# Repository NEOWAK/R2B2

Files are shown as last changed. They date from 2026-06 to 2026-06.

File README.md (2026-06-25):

# R2B2

    

## 📑 Table of Contents

- [Description](#description)
- [Screenshots](#screenshots)
- [Quick Start](#quick-start)
- [Project Structure](#project-structure)
- [Contributors](#contributors)
- [Contributing](#contributing)
- [License](#license)

## 📝 Description

R2B2 — Robot autonome ramasseur de balles de tennis

## 📸 Screenshots

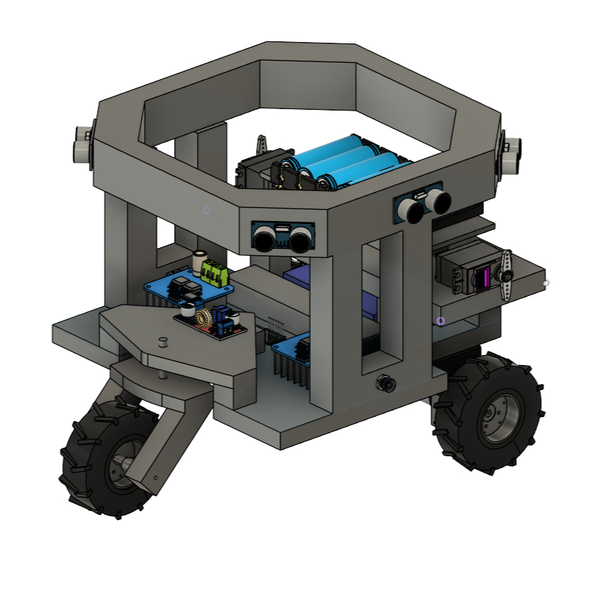
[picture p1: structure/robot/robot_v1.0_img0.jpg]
robot 3D


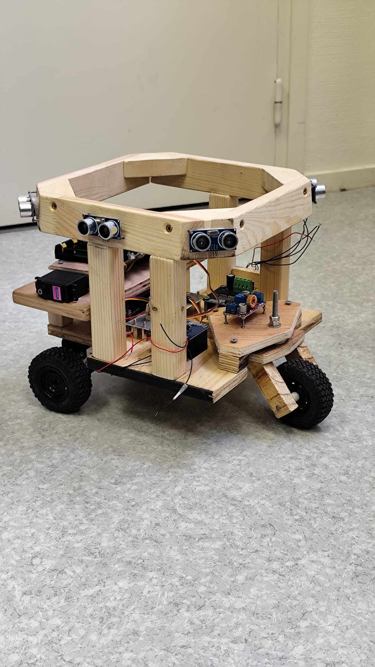
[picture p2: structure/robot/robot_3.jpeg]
robot real


## ⚡ Quick Start

```bash

# 1. Clone the repository
git clone https://github.com/NEOWAK/R2B2.git

# See the Development Setup section below
```

## 📁 Project Structure

```
.
├── LICENSE
├── docs
│   ├── cdc
│   │   ├── Rapport_CDC.pdf
│   │   └── Rapport_CDC.zip
│   ├── presentation
│   │   ├── R2B2.pdf
│   │   └── R2B2.pptx
│   └── rapport
│       ├── Rapport_PROJET.zip
│       └── Rapport_PROJETELEC_ROBOT_TENNIS.pdf
├── firmware
│   ├── esp32c3
│   │   ├── v0_1.ino.ino
│   │   └── v0_2.ino.ino
│   └── fpga
│       ├── driver
│       │   └── Motor_Controller.vhd
│       ├── pid
│       │   ├── adc0
│       │   │   ├── adc0.bsf
│       │   │   ├── adc0.cmp
│       │   │   ├── adc0.html
│       │   │   ├── adc0.ppf
│       │   │   ├── adc0.xml
│       │   │   ├── adc0_bb.v
│       │   │   ├── adc0_generation.rpt
│       │   │   ├── adc0_inst.v
│       │   │   ├── adc0_inst.vhd
│       │   │   └── synthesis
│       │   │       └── ...
│       │   ├── adc0.qsys
│       │   ├── adc0.sopcinfo
│       │   ├── adc_period.vhd
│       │   ├── baud_gen.vhd
│       │   ├── motor_controller.vhd
│       │   ├── top.vhd
│       │   ├── uart_framer.vhd
│       │   ├── uart_mux.vhd
│       │   ├── uart_rx.vhd
│       │   ├── uart_tx.vhd
│       │   ├── xor.qpf
│       │   ├── xor.qsf
│       │   ├── xor.qws
│       │   └── xor_assignment_defaults.qdf
│       ├── pince
│       │   └── pince_controlleur.vhd
│       └── ultrason
│           └── ultrason.vhd
├── hardware
│   ├── alimentation
│   │   ├── alimentation_0.heic
│   │   └── alimentation_1.heic
│   ├── cao
│   │   ├── pince.f3z
│   │   └── robot.f3z
│   └── pcb
│       ├── pads_layout.pdf
│       ├── pads_logic.pdf
│       ├── pcb.cir
│       ├── pcb.sch
│       ├── pcb_v1.pcb
│       └── pcb_v2.pcb
├── scripts
│   └── courbe_paramétrique.ggb
├── software
│   ├── dashbord
│   │   ├── Capture d’écran du 2026-05-18 06-51-23.png
│   │   └── dashboard.py
│   ├── detection
│   │   ├── esp32_camera.ino
│   │   └── modele_ia.zip
│   └── monitor
│       ├── img
│       │   ├── adc_mesure_5V.png
│       │   ├── adc_mesure_paliers.png
│       │   └── oscilo_mesure_5V.BMP
│       ├── monitor.py
│       └── monitor_v2.py
└── structure
    ├── pince
    │   ├── Capture d’écran du 2026-05-18 06-07-12.png
    │   ├── Capture d’écran du 2026-05-18 06-07-25.png
    │   ├── Capture d’écran du 2026-05-18 06-07-59.png
    │   ├── Capture d’écran du 2026-05-18 06-08-07.png
    │   ├── pince3D_01_square.jpg
    │   └── pinceo.jpg
    └── robot
        ├── robot_0.jpeg
        ├── robot_1.jpeg
        ├── robot_2.jpeg
        ├── robot_3.jpeg
        └── robot_v1.0_img0.jpg
```

## 👥 Contributors

Thanks to everyone who has contributed to this project:

<p align="left">
<a href="https://github.com/NEOWAK" title="NEOWAK">NEOWAK</a>
</p>

[See the full list of contributors →](https://github.com/NEOWAK/R2B2/graphs/contributors)

## 👥 Contributing

Contributions are welcome! Here's the standard flow:

1. **Fork** the repository
2. **Clone** your fork: `git clone https://github.com/NEOWAK/R2B2.git`
3. **Branch**: `git checkout -b feature/your-feature`
4. **Commit**: `git commit -m 'feat: add some feature'`
5. **Push**: `git push origin feature/your-feature`
6. **Open** a pull request

Please follow the existing code style and include tests for new behavior where applicable.

## 📜 License

This project is licensed under the **MIT** License.

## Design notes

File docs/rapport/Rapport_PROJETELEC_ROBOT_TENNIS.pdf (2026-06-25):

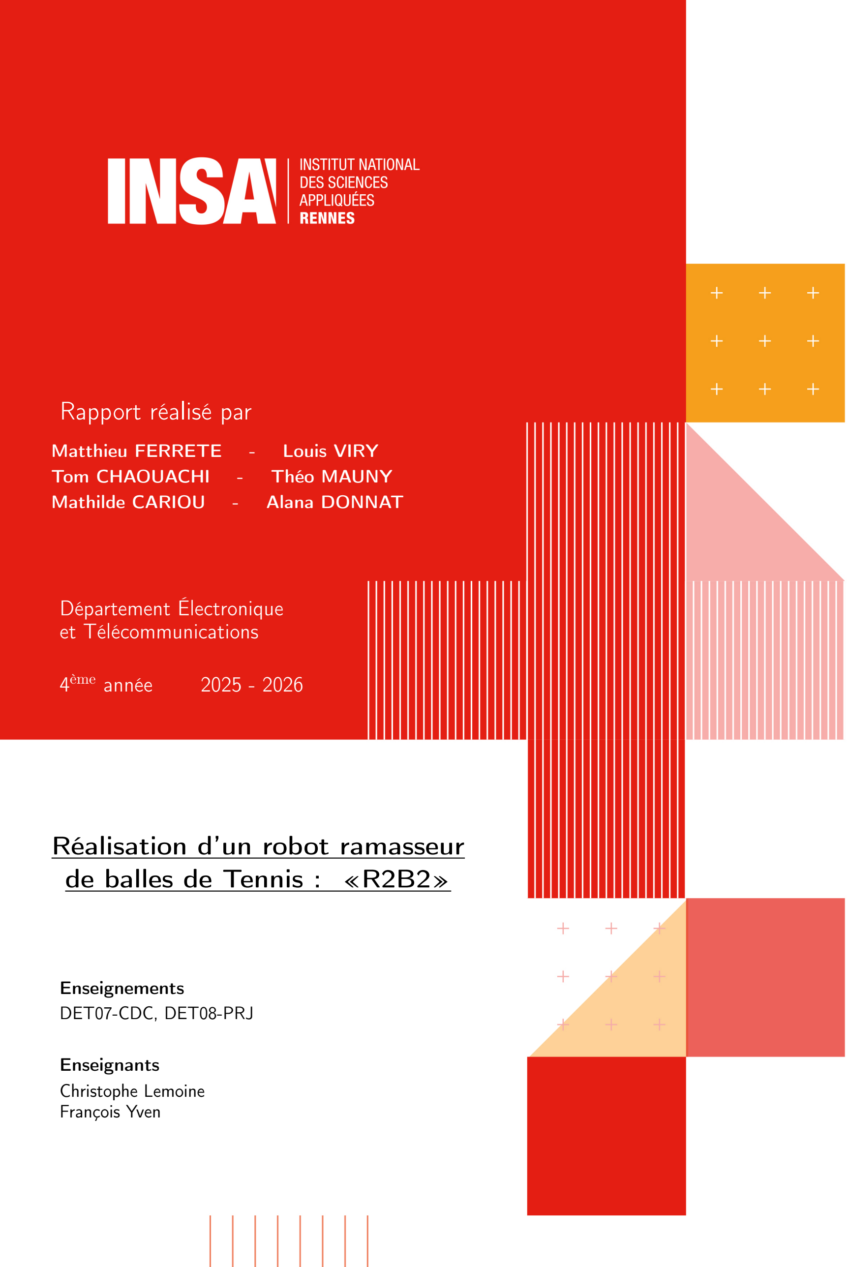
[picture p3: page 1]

## Rapport réalisé par

Matthieu FERRETE | - | Louis VIRY
Tom CHAOUACHI | - | Théo MAUNY
Mathilde CARIOU | - | Alana DONNAT

## Département Électronique et Télécommunications

4

## ème année 2025 - 2026

## Réalisation d’un robot ramasseur de balles de Tennis : «R2B2»

Enseignements
DET07-CDC, DET08-PRJ

Enseignants
Christophe Lemoine
François Yven

# Remerciements

Nous tenons à remercier les enseignants qui encadrent ce projet pour leur accompagnement tout au long de cette année.

Nous remercions M. Christophe LEMOINE pour son encadrement pédagogique et M. François YVEN pour son suivi en tant que tuteur de projet.

Nous tenons à adresser nos remerciements les plus sincères à M. Gilles PICOULT, dont la présence a été déterminante dans la progression de ce projet. Ses conseils techniques avisés, sa disponibilité, les solutions qu’il nous a proposées face aux difficultés rencontrées, la fabrication des PCB, ainsi que ses encouragements ont été d’une valeur inestimable tout au long de la réalisation de R2B2.

R2B2

### Robot Ramasseur de Balles de Tennis

# Table des matières

1 Introduction | 7
2 Présentation du projet | 7
3 Cahier des charges | 13
4 Architecture générale du système | 16

5 Module de déplacement et motorisation | 19
5.3.2 | Première approche : circuit de conditionnement analogique (non conservé) | 23
6 Module de détection et navigation | 28
7 Conception mécanique et CAO | 34

8 Système de batteries et gestion d’énergie | 40
9 Supervision et interface opérateur | 42
10 Gestion | 46
11 Démonstration | 50

12 Conclusion | 54
13 Bibliographie | 55

# 1. Introduction

L’évolution technologique dans le domaine du sport a considérablement transformé la pratique de haut niveau comme celle des amateurs. Si les équipements ont bénéficié d’innovations majeures en science des matériaux, la logistique même du jeu de tennis est restée remarquablement classique : la gestion des balles sur le terrain repose encore presque exclusivement sur l’intervention humaine.

Le tennis est un sport structurellement fragmenté : le temps de jeu effectif ne représente qu’une fraction minime du temps total, déséquilibre encore aggravé lors des entraînements amateurs où le ramassage des balles peut mobiliser jusqu’à 20% à 30% d’une séance. Ces balles immobiles constituent par ailleurs un risque physique avéré, une part significative des blessures survenant non pas à cause de l’effort, mais par un appui instable sur une balle qui traîne.

La dimension inclusive mérite également d’être soulignée : pour les joueurs en fauteuil roulant, le ramassage impose des manœuvres supplémentaires et une flexion du tronc qui peut s’avérer éprouvante, voire impossible selon la pathologie du joueur.

Notre projet, baptisé R2B2, vise à concevoir une solution mécatronique autonome opérant en continu durant le match. Contrairement aux rares solutions existantes qui nettoient le terrain en fin de session, R2B2 cohabite avec les joueurs, identifie les balles mortes et les collecte en temps réel, sans jamais interférer avec le jeu ni gêner les déplacements des sportifs — ce qui impose des contraintes fortes en détection, navigation, sécurité et réactivité.

Ce document présente la démarche de conception de R2B2 : après une analyse du besoin et un état de l’art, nous décrirons l’architecture générale puis chacun des sous-systèmes — déplacement, détection, ramassage, gestion d’énergie et supervision — avant de conclure par le bilan et les perspectives d’évolution.

# 2. Présentation du projet

## 2.1 Analyse du besoin

Pour justifier la pertinence de ce projet, nous avons analysé les impacts du ramassage manuel sous trois angles fondamentaux : l’efficacité temporelle, la sécurité physique et l’inclusion sociale.

### 2.1.1 Optimisation du temps de jeu

Le tennis souffre d’un ratio temps de jeu sur temps de présence particulièrement faible. Une étude statistique relayée par le Wall Street Journal a mis en lumière que sur une rencontre professionnelle d’une durée de trois heures, le temps de jeu effectif ne représente que 17,5% du temps total, soit à peine 21 minutes d’action réelle [1].

Ce constat est encore plus sévère lors des entraînements amateurs. Lorsqu’un joueur effectue une série de services ou un exercice au panier, le ramassage manuel des 50 à 100 balles dispersées peut prendre entre 5 et 8 minutes. Sur une séance d’une heure, la répétition de cette tâche empiète sur le temps de pratique de 20% à 30%. L’automatisation de ce processus permettrait de récupérer ce temps perdu pour le consacrer à l’apprentissage technique et au plaisir du jeu.

### 2.1.2 Sécurité et prévention des blessures

La présence de balles immobiles sur la surface de jeu constitue un risque avéré pour l’intégrité physique des joueurs. Les déplacements au tennis sont caractérisés par des courses latérales, des reprises d’appuis violentes et des reculs précipités pour se replacer en fond de court. Une part significative des accidents survient non pas à cause de l’effort lui-même, mais par un appui instable sur une balle qui traîne.

Si un joueur pose le pied sur une balle lors d’un de ces mouvements, la cheville subit une torsion immédiate. Selon les données de la Fédération Française de Tennis et des études en traumatologie sportive, l’entorse de la cheville représente environ 25% des blessures recensées au tennis [2]. En assurant un nettoyage continu de la zone d’évolution, notre robot agit comme un dispositif de sécurité active permettant de réduire fortement la probabilité de chute et de lésion ligamentaire.

### 2.1.3 Accessibilité et Handisport

L’aspect inclusif est un pilier central de notre réflexion. Pour les joueurs de tennis en fauteuil roulant, la contrainte du ramassage est décuplée. La biomécanique du ramassage en position assise impose des manœuvres supplémentaires avec le fauteuil et une flexion du tronc qui peut s’avérer éprouvante physiquement, voire impossible selon la pathologie du joueur.

Cette difficulté constitue parfois un frein à la pratique ou une source de découragement pour les débutants. En déléguant cette tâche à un système autonome, nous redonnons de l’autonomie aux joueurs en situation de handicap, leur permettant de se focaliser uniquement sur leur performance sportive et leur plaisir de jeu, sans dépendre d’une tierce personne.

## 2.2 État de l’art

Avant de définir notre solution, nous avons étudié les technologies existantes — manuelles et automatisées — afin d’identifier les lacunes du marché actuel et les bonnes pratiques à conserver.

### 2.2.1 Les solutions manuelles

- Le tube de ramassage

C’est un tube en plastique ou en métal muni d’un clapet anti-retour. Pour faire entrer la balle, on appuie simplement dessus.

Avantage : Très peu coûteux (moins de 20 €), facilement transportable, évite de se baisser complètement.
Inconvénient : Effort physique répétitif, ramassage balle par balle, aucune automatisation possible.
- Le rouleau de ramassage

Il s’agit d’un rouleau que l’on pousse sur le court, conçu avec des barreaux souples qui s’écartent lorsqu’on roule sur une balle, permettant de la récupérer et de la stocker dans un panier intégré.

Avantage : Ramassage rapide, grande capacité de stockage (jusqu’à 60 balles). Inconvénient : Encombrant, nécessite toujours une action humaine continue, inutilisable pendant le jeu.

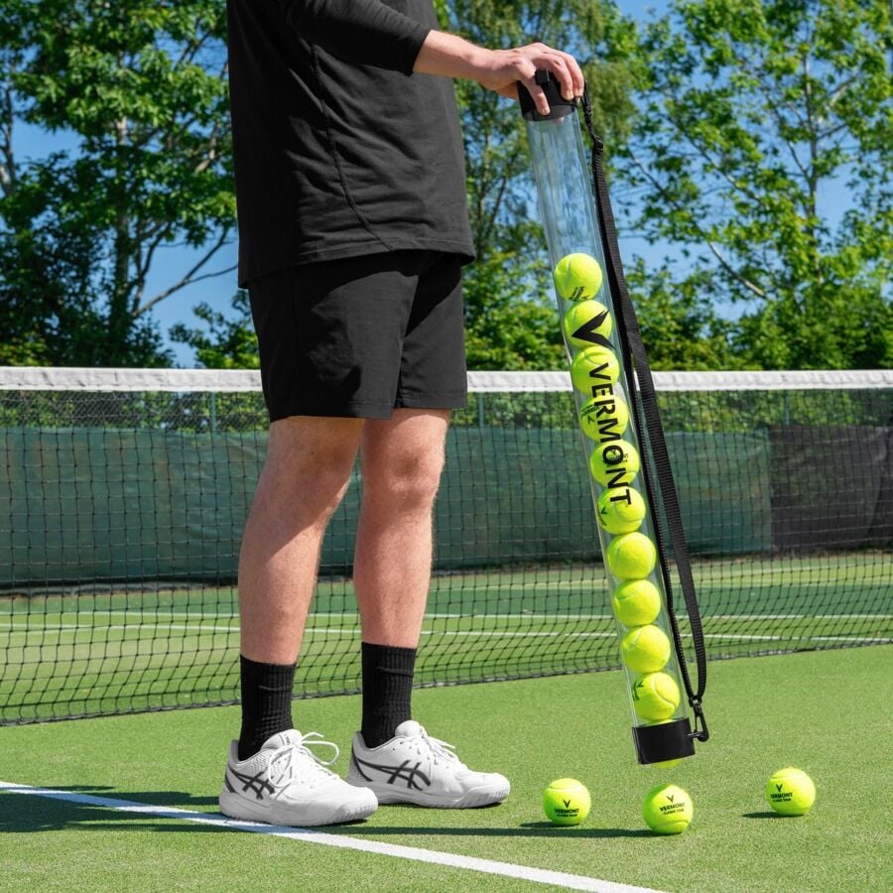
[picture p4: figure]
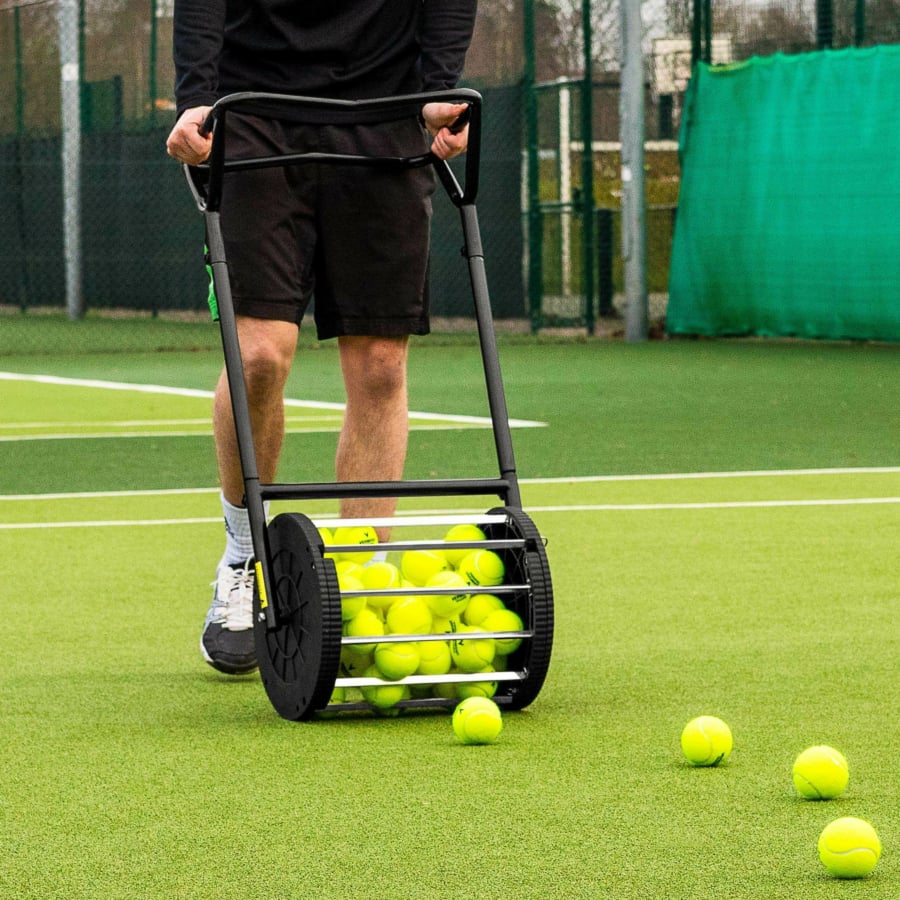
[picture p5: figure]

Figure 1 – Tube de ramassage | Figure 2 – Rouleau de ramassage

### 2.2.2 Les solutions automatisées

- Le Tennibot

Robot ramasseur autonome dont le fonctionnement s’inspire de l’aspirateur robot, adapté au tennis. Son système de navigation repose sur l’intelligence artificielle et un LIDAR 360° offrant une portée de 30 mètres [3].

Avantage : Autonomie totale — le joueur joue pendant que le robot ramasse. Inconvénient : Prix prohibitif pour un usage amateur (˜2 245 $), vitesse de ramassage lente, capacité de stockage limitée, opération uniquement hors-match.

- Le Slinger Bag

Système robotisé permettant la distribution de balles selon plusieurs paramètres : fréquence, vitesse, effets.

Avantage : Sessions d’entraînement personnalisées sans partenaire.
Inconvénient : Conçu exclusivement pour la distribution — aucune fonction de collecte.

L’utilisateur doit interrompre l’entraînement pour ramasser manuellement les balles et recharger la machine.

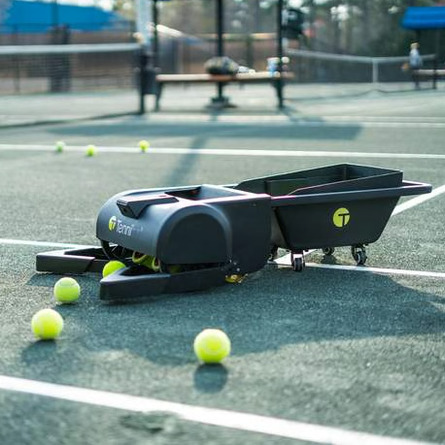
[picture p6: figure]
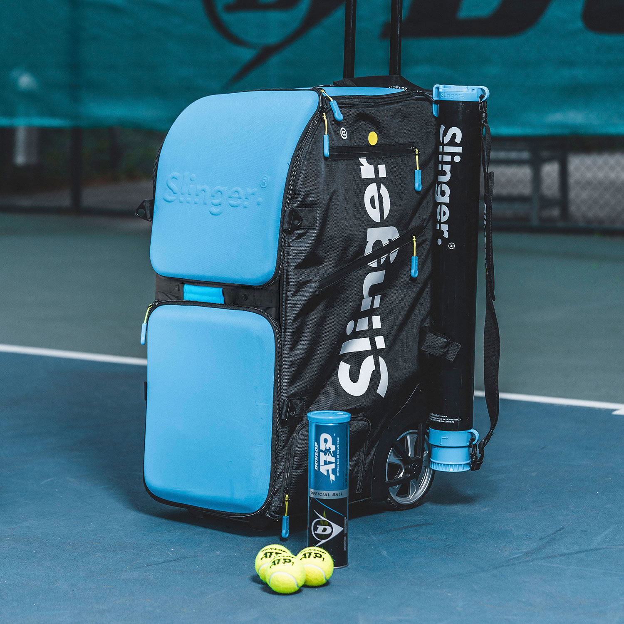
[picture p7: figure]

Figure 3 – Tennibot | Figure 4 – Slinger Bag

### 2.2.3 Positionnement de R2B2

Il apparaît que les systèmes existants présentent des limites structurelles majeures. Les outils manuels imposent une charge physique répétitive et interrompent systématiquement le jeu. Les solutions automatisées comme le Tennibot affichent un coût prohibitif et opèrent uniquement entre les sessions, pas pendant le match.

R2B2 répond à une lacune claire : aucune solution actuelle n’est à la fois abordable financièrement, capable d’opérer en temps réel pendant le jeu, et respectueuse de la sécurité des joueurs. C’est précisément l’objectif que notre projet se donne.

## 2.3 Solution retenue

Pour répondre aux besoins identifiés, notre projet se fixe quatre objectifs techniques précis qui ont guidé l’ensemble des choix de conception.

### 2.3.1 Sécurité et détection

La priorité absolue est la cohabitation homme-machine. Le robot doit cartographier son environnement immédiat pour distinguer une balle inerte d’un joueur en mouvement. Si un humain pénètre dans un rayon de 1 mètre autour du robot, le système doit déclencher un arrêt total ou une manœuvre d’évitement. La chaîne de traitement allant de la détection à l’arrêt des moteurs doit respecter une latence inférieure à 100 millisecondes, validée expérimentalement à 85 ms lors de nos tests.

### 2.3.2 Compacité et discrétion

Le robot ne doit pas devenir une nuisance visuelle ni perturber les joueurs. Sa hauteur totale est contenue sous 25 cm, lui permettant de circuler librement sous le filet et de rester hors du champ de vision direct des joueurs lors des phases de frappe. L’architecture à entraînement différentiel sur trois roues permet des demi-tours instantanés sans avance, indispensables pour s’extraire des coins du court. La motorisation est isolée phoniquement pour rester sous le seuil des 50 dB.

### 2.3.3 Performances et autonomie

Pour être efficace entre deux points, le robot doit être rapide. Une vitesse de pointe de 3 m/s est atteinte, permettant d’intervenir rapidement durant les temps morts.

L’alimentation repose sur un pack 7S1P composé de cellules Samsung INR18650-25R, offrant une tension nominale de 25,9 V (29,4 V en charge complète, coupure à 17,5 V) pour une capacité de 2 500 mAh, soit une énergie totale disponible d’environ 64,75Wh. Cette configuration garantit une autonomie suffisante pour couvrir la durée moyenne d’un match complet, tout en délivrant un courant de décharge continu pouvant atteindre 20 A pour alimenter les pics de consommation des moteurs.

### 2.3.4 Ramassage

Le système de ramassage doit être universel et robuste. Le taux de réussite de la collecte au premier passage doit dépasser 90%, même si la balle est encore légèrement en mouvement. Le réservoir embarqué est dimensionné pour contenir entre 10 et 15 balles, correspondant à la quantité généralement utilisée lors d’un cycle de jeu avant un ramassage complet.

# 3. Cahier des charges

## 3.1 Contraintes fonctionnelles

Le tableau suivant synthétise les exigences fonctionnelles retenues pour R2B2, issues de l’analyse du besoin conduite au semestre précédent.

Fonction | Exigence | Justification

Vitesse de déplacement

≥ 3 m/s, atteinte en <
4 s
Intervenir | efficacement | entre
deux points
Gabarit | Hauteur ≤ 25 cm | Passer librement sous le filet
(hauteur 91 cm au centre)
Autonomie | ≥ 2 h | Couvrir la durée moyenne d’un
match complet
Niveau sonore | ≤ 50 dB | Ne pas perturber la concentra-
tion des joueurs
Taux de collecte | ≥ 90% au 1er passage | Fiabilité opérationnelle en condi-
tion réelle
Capacité du réservoir
10 à 15 balles | Correspondance avec un cycle de
jeu standard
Budget | ≤ 120 € | Contrainte imposée par le cadre
pédagogique

Table 1 – Contraintes fonctionnelles de R2B2

## 3.2 Contraintes techniques

### 3.2.1 Niveaux logiques et alimentation

L’architecture électronique de R2B2 repose sur une cohabitation de deux domaines de tension. Le FPGA DE10-Lite opère en logique 3,3 V, tandis que les capteurs ultrasons HC-SR04 délivrent leurs signaux Echo en 5 V. Un pont diviseur résistif (R1 = 3,3 kΩ, R2 = 1,8 kΩ) est donc interposé sur chaque ligne Echo pour adapter les niveaux sans endommager les entrées du FPGA.

L’ensemble du système est alimenté par le pack 7S1P Samsung INR18650-25R (25,9 V nominal). Des régulateurs de tension assurent la distribution aux différents sous-systèmes selon leurs besoins propres.

### 3.2.2 Architecture de contrôle hybride

La répartition des tâches entre les deux cartes principales découle d’une contrainte forte : certaines opérations exigent un déterminisme temporel strict que seul un FPGA peut garantir.

- FPGA DE10-Lite : gestion temps réel des signaux PWM moteurs, lecture des encodeurs à effet Hall, pilotage des 8 capteurs ultrasons, asservissement PID.
- XIAO ESP32-C3 : logique décisionnelle de haut niveau — navigation, gestion des trajectoires, réception des coordonnées de balle depuis la caméra, relais des données de supervision vers le PC.
- XIAO ESP32-S3 Sense : acquisition et traitement d’image, pilotage du servomoteur SG90, calcul du barycentre et transmission des coordonnées.

### 3.2.3 Protocoles de communication

Les échanges inter-cartes reposent exclusivement sur l’UART, choisi pour sa simplicité d’implémentation en VHDL et sa robustesse. La trame définie entre le FPGA et l’ESP32-C3 est constituée de 8 octets : un octet de start, un octet d’état (déplacement / bras / pince), un octet de sens de marche, deux octets de consigne de vitesse et deux octets d’angle de braquage.

## 3.3 Ajustements stratégiques en cours de projet

Le périmètre fonctionnel initial a évolué au fil des réunions d’avancement. Chaque abandon a été motivé par une analyse coût-bénéfice rigoureuse, privilégiant la fiabilité du cœur de fonctionnalité sur l’exhaustivité des options.

### 3.3.1 Fonctionnalités abandonnées en début de projet

Trois fonctionnalités initialement envisagées ont été retirées dès la première révision du Gantt, le projet ayant été jugé trop ambitieux au regard du calendrier disponible [1] :

- Détection sonore des balles : l’idée d’exploiter le son d’impact balle-sol a été écartée en raison de la complexité du traitement du signal en environnement bruité extérieur (vent, bruits de match), et parce que la vision s’est révélée plus précise et moins énergivore.
- Renvoi des balles ramassées : un mécanisme de relance avait été envisagé, mais sa conception mécanique dépassait le budget et le temps disponible sans apporter de valeur déterminante à la démonstration.
- Base deux roues auto-équilibrée : le robot était initialement prévu sur deux roues avec un système de contre-balancement. Cette solution a été abandonnée car la correction continue de l’inclinaison complexifiait fortement la détection et le ramassage. Le passage à trois roues (deux motrices à l’avant, une roue folle à l’arrière) a permis de conserver l’agilité tout en garantissant la stabilité.

### 3.3.2 Remplacement du microcontrôleur principal

En cours de développement, le microcontrôleur XIAO MG24 initialement retenu pour la logique décisionnelle a présenté un dysfonctionnement matériel ne permettant plus son utilisation. Afin de ne pas bloquer l’avancement du projet, il a été remplacé par un XIAO ESP32-C3 disponible en stock.

Ce choix s’est avéré pertinent : l’ESP32-C3 offre des capacités comparables pour notre usage — communication UART, logique de navigation, gestion des entrées/sorties — sans nécessiter de refonte architecturale. L’ensemble du protocole de communication défini avec le MG24 a été conservé tel quel.

# 4. Architecture générale du système

## 4.1 Schéma de principe général

Le robot repose sur une architecture trois niveaux : acquisition sensorielle, traitement décisionnel et actionnement. Deux microprocesseurs et un FPGA se répartissent les tâches selon leur nature — temps réel strict, traitement d’image et logique de navigation — et communiquent par liaisons série UART.

Durant la phase de conception, le port USB-UART natif de l’ESP32-C3 a servi d’interface de débogage principale. Les variables internes — angle de consigne, distance estimée, état du robot — étaient transmises en continu vers un terminal série, permettant de valider le comportement du système sans instrumentation matérielle supplémentaire. Ce canal n’est pas utilisé en conditions opérationnelles.

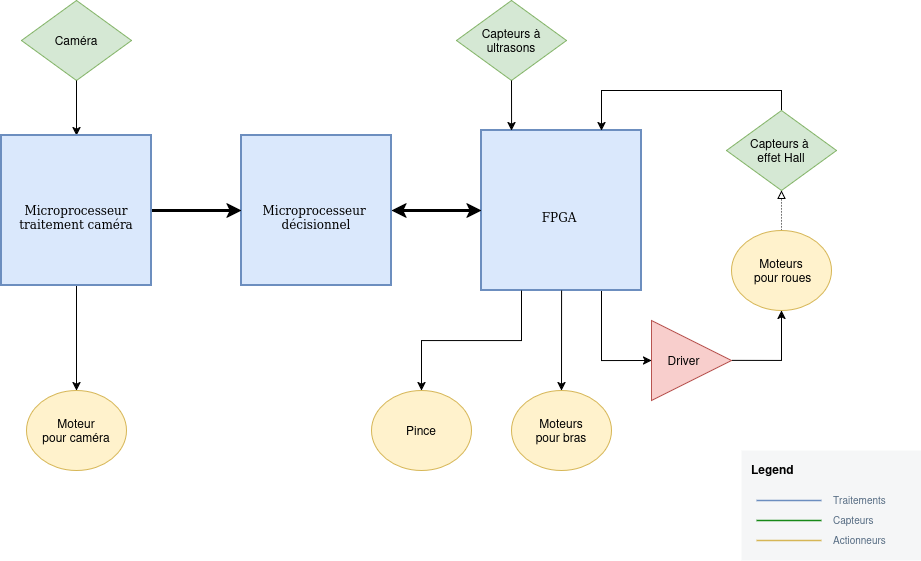
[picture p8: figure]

Figure 5 – Schéma de principe général du robot ramasseur de balles

## 4.2 Architecture de contrôle hybride FPGA + Microcontrôleur

La répartition des tâches repose sur les caractéristiques intrinsèques de chaque unité : le FPGA DE10-Lite assure la logique câblée déterministe (PID, PWM, capteurs, sécurité) en parallèle à 50 MHz, tandis que le XIAO ESP32-C3 gère la logique décisionnelle de haut niveau — navigation, séquences de collecte, arbitrage des ordres issus du module caméra.

### 4.2.1 Chaîne de perception visuelle

Un microprocesseur dédié au traitement caméra (XIAO ESP32-S3 Sense) acquiert les images via l’OV3660 et exécute l’inférence FOMO. Il transmet à l’ESP32-C3 l’angle de rotation et le seuil de distance de la balle détectée. Un moteur orienteur de caméra permet d’ajuster le champ de vision selon les consignes reçues.

### 4.2.2 Couche décisionnelle et temps réel

L’ESP32-C3 interprète les données caméra et sélectionne la stratégie courante — recherche, approche ou ramassage. Il transmet ses ordres au FPGA DE10-Lite qui les exécute en temps réel :

— Régulation PID — asservissement en vitesse de chaque roue à partir des capteurs à effet Hall ; les deux boucles s’exécutent simultanément grâce au parallélisme natif du FPGA — Génération PWM — signaux à 20 kHz pour le pont en H, avec gestion indépendante de la vitesse et du sens de rotation de chaque moteur
— Acquisition ultrason — pilotage des 8 capteurs HC-SR04 en parallèle et déclenchement de l’évitement obstacles sous 200 mm
— Séquencement de la pince — Machine à états gérant l’ouverture, la fermeture et la sécurité thermique du moteur pas à pas 28BYJ-48
— Arrêt d’urgence matériel — signal asynchrone KEY0 forçant l’extinction de tous les actionneurs en moins de 20 ns

### 4.2.3 Chaîne d’actionnement

Le FPGA pilote trois actionneurs distincts :
— Moteurs de roues — via un driver pont en H, asservis en boucle fermée PID grâce aux capteurs à effet Hall
— Moteurs de bras — déclenchés au franchissement du seuil BBOX_NEAR
— Pince — moteur pas à pas 28BYJ-48 en mode demi-pas (8 phases) pour maximiser le couple lors de la saisie

## 4.3 Outils et environnements de développement

### 4.3.1 FPGA — Intel Quartus Prime

La logique VHDL du DE10-Lite est développée sous Intel Quartus Prime Lite, certains modules ayant été simulés sous ModelSim avant intégration dans le Top_Robot pour valider chronogrammes et machines à états sans déploiement matériel systématique.

### 4.3.2 Microcontrôleurs — Arduino IDE

Les deux ESP32 sont programmés en C/C++ sous Arduino IDE avec le BSP Seeed Studio. Le modèle FOMO est déployé sous forme de bibliothèque C++ générée par Edge Impulse Studio et embarquée directement dans le firmware de l’ESP32-S3.

### 4.3.3 Supervision PC — Python

Un script Python lit le port série de l’ESP32-C3 et trace en temps réel vitesse, angle et état du robot via matplotlib, permettant de diagnostiquer les dérives PID et valider les seuils de détection sans modifier le firmware.

### 4.3.4 Conception mécanique — Autodesk Fusion 360

Le châssis et les pièces mécaniques sont modélisés sous Autodesk Fusion 360 (licence éducation). Le positionnement des composants électroniques et des capteurs est validé dans l’assemblage CAO avant toute réalisation physique.

# 5. Module de déplacement et motorisation

Le module de déplacement repose sur une chaîne de contrôle entièrement implémentée en VHDL sur le FPGA DE10-Lite, dont l’architecture est présentée en Figure 6. Une trame UART reçue de l’ESP32-C3 est décodée pour en extraire la consigne de vitesse. Celle-ci est comparée à la vitesse mesurée, fournie par le bloc Frequency extractor alimenté par le Rotation counter issu du capteur Hall. Le régulateur PI calcule la commande correctrice transmise au Driver BTS7960, qui alimente directement les moteurs. Les sections suivantes détaillent chacun de ces blocs.

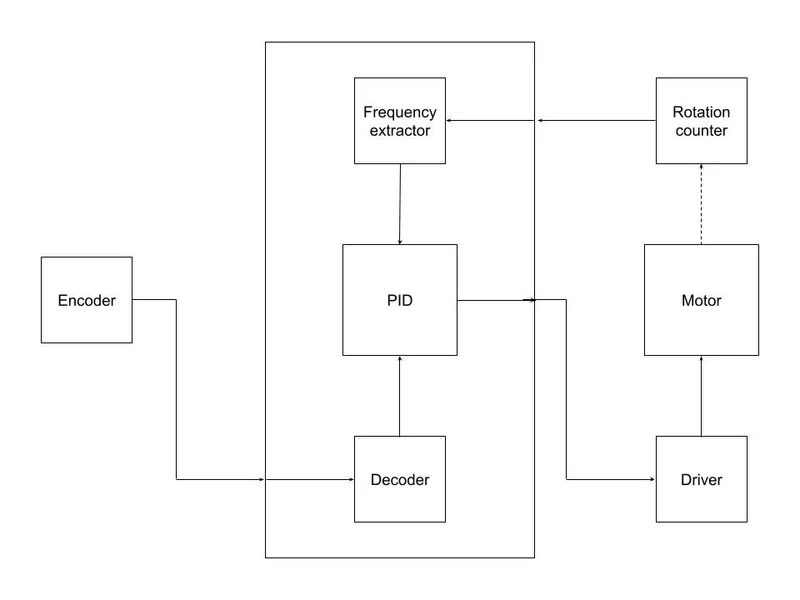
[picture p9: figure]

Figure 6 – Architecture de la chaîne de contrôle moteur sur FPGA

## 5.1 Choix et dimensionnement des actionneurs

### 5.1.1 Expression du besoin mécanique

Pour intervenir efficacement entre deux points et ne pas perturber le rythme du jeu, le robot doit atteindre une vitesse de pointe de 3 m/s — exigence fixée par le cahier des charges afin de garantir une expérience de jeu fluide et continue. Avec des roues de diamètre D = 75 mm, la vitesse de rotation minimale requise est :

nmin =

60 · v
π · D

=

60 × 3
π × 0,075

≈ 764 RPM

En tenant compte des frottements et du rendement du réducteur (η ≈ 0,75), le couple utile à délivrer est estimé à supérieur à 1 N.m par moteur.

### 5.1.2 Sélection et validation : JGB37-520 24 V 960 RPM

Le JGB37-520 24 V — 960 RPM satisfait l’ensemble des contraintes. Sa vitesse à vide produit une vitesse linéaire théorique :

vmax =

960 × π × 0,075
60

≈ 3,77 m/s

soit une marge de +25% au-dessus du seuil requis, absorbant les pertes en charge réelle. Son couple nominal de 1,5 N.m dépasse le besoin estimé, sa masse de 160 g reste compatible avec le gabarit du châssis, et son alimentation en 24 V est assurée directement par le pack batterie 7S (25,9 V nominal).

## 5.2 Pièces imprimées dédiées aux actionneurs

### 5.2.1 Adaptateur roue-moteur

L’arbre de sortie du JGB37-520 présente une section cylindrique à méplat — un cylindre tronqué sur un quart de sa longueur — incompatible avec le logement hexagonal natif de la roue. Une pièce adaptatrice a donc été conçue et imprimée en PETG pour assurer la liaison entre les deux.

L’adaptateur reprend en négatif la géométrie exacte de l’arbre côté moteur, et présente un profil hexagonal côté roue, transmettant ainsi le couple sans jeu angulaire. Le PETG a été retenu pour sa rigidité, sa résistance aux contraintes mécaniques répétées et sa bonne tolérance dimensionnelle à l’impression.

### 5.2.2 Couronne magnétique sur l’arbre moteur

Pour mesurer la vitesse de rotation, une couronne d’aimants N45 est fixée directement sur l’arbre moteur. Les aimants sont disposés en alternance de polarité Nord/Sud sur la circonférence, générant un signal périodique détectable par le capteur à effet Hall SS49E placé en regard. Avec 6 aimants répartis uniformément, la fréquence du signal Hall est directement proportionnelle à la vitesse de rotation :

f =

n × Naimants
60

Le moteur opérant dans la plage [0 ; 960]tr/min, la fréquence lue par le capteur évolue dans la plage :

f ∈

0 × 6
60

;

960 × 6

60
= [0 ; 96] Hz

Cette plage de 96 Hz offre une granularité suffisante pour estimer la vitesse du robot avec une bonne précision sur l’ensemble de la plage de fonctionnement — y compris aux faibles régimes où l’asservissement PID est le plus sensible aux erreurs de mesure. Elle est par ailleurs largement compatible avec la fréquence d’échantillonnage du FPGA (50 MHz), garantissant une acquisition sans aliasing ni perte d’impulsion. La couronne a été imprimée en PETG avec des logements calibrés pour maintenir les aimants sans adhésif.

### 5.2.3 Support SS49E

Le capteur à effet Hall SS49E doit être maintenu à distance fixe et constante de la couronne magnétique pour garantir la répétabilité de la mesure. Un support dédié a été conçu et imprimé en PETG pour répondre à cette contrainte.

La pièce se compose d’une platine de fixation percée d’un trou de vissage permettant de solidariser l’ensemble au châssis moteur, et d’une équerre triangulée qui positionne la face active du SS49E perpendiculairement à l’axe de rotation. La triangulation assure la rigidité de l’équerre et supprime tout risque de flexion susceptible de modifier la distance capteur/aimants.

Le logement calibré pour le boîtier TO-92 intègre trois fentes individuelles pour les broches, garantissant un positionnement angulaire reproductible. Le capteur est maintenu en position par du ruban adhésif appliqué sur sa face supérieure. La profondeur du logement est calculée pour placer la face active du capteur à 2,5 mm de la surface des aimants, distance comprise dans la plage de fonctionnement optimal du SS49E et assurant un niveau de champ suffisant pour discriminer clairement les alternances Nord/Sud de la couronne.

## 5.3 Mesure de vitesse par capteur à effet Hall SS49E

### 5.3.1 Principe de mesure et choix du capteur

La mesure de vitesse repose sur la détection du champ magnétique alternatif généré par le passage successif de pôles Nord et Sud devant la face active d’un capteur à effet Hall linéaire SS49E. La fréquence du signal produit est directement proportionnelle à la vitesse de rotation de la roue — deux approches d’implémentation ont été étudiées et sont détaillées dans les sections suivantes.

Ce capteur, ratiométrique, délivre une tension de repos égale à la moitié de son alimentation (V0 ≈ 2,5 V sous 5 V), qui croît ou décroît proportionnellement au champ perçu, avec une sensibilité de l’ordre de 1,4 à 1,8 mV/G.

### 5.3.2 Première approche : circuit de conditionnement analogique (non conservé)

La première implémentation consistait à placer le SS49E directement contre le carter du moteur JGB37-520, en exploitant le champ des aimants du rotor interne. Le signal mesuré n’excédait
pas 2,5 mVpp — amplitude trop faible pour être exploitée directement par l’ADC du FPGA.

L’objectif de la chaîne de conditionnement était de produire en sortie un signal créneaux dont chaque front — montant ou descendant — correspond à un quart de tour de roue, permettant au FPGA de comptabiliser les impulsions et d’en déduire la vitesse.
La chaîne conçue à cet effet comprend trois étages : prétraitement (gain 56), dérivation et mise en forme vers 3,3 V.
Le circuit a été intégralement routé sous PADS Logic et PADS Layout puis fabriqué sur PCB (Figure 7). Les tests ont d’abord validé le fonctionnement de la carte en simulant l’entrée SS49E par un générateur de fonctions à 2,5 mVpp : la chaîne délivrait bien un signal créneaux propre en sortie. En revanche, le passage au capteur réel n’a jamais abouti malgré plusieurs jours de débogage — le bruit de fond et l’instabilité du signal source réel se sont révélés incompatibles avec le gain élevé de la chaîne.

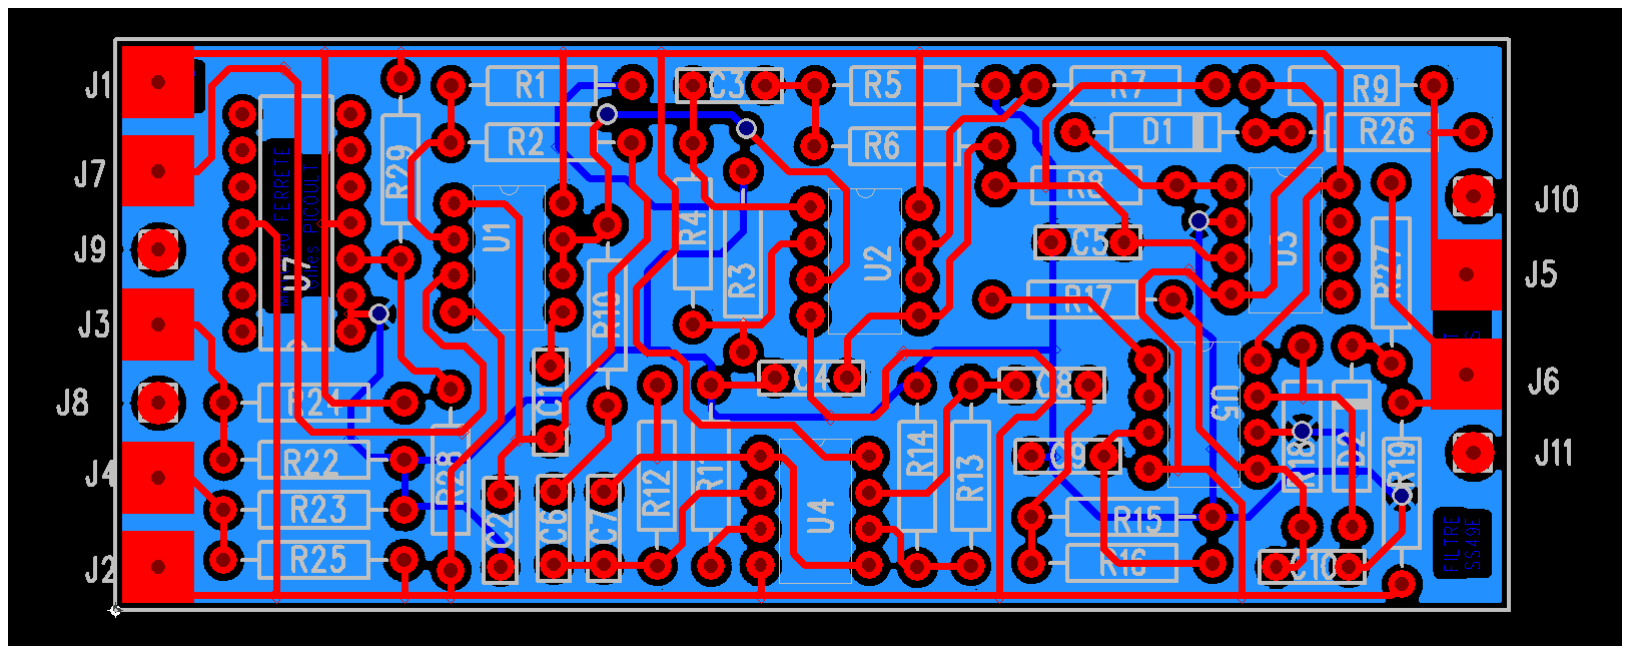
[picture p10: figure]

Figure 7 – Routage PCB du circuit de conditionnement — PADS Layout

Après trois semaines de développement, la décision d’abandon a été actée : l’architecture à couronne magnétique externe (section 5.2.2) s’affranchit du problème à la source en fournissant un signal d’amplitude suffisante, sans recourir à un conditionnement analogique de précision.

### 5.3.3 Solution retenue : acquisition ADC sur FPGA en VHDL

L’abandon du conditionnement analogique a conduit à une refonte complète de l’approche. La couronne magnétique externe (section 5.2.2) fournit un signal d’amplitude suffisante pour être échantillonné directement par l’ADC 12 bits du DE10-Lite, via l’IP dédiée du programme étudiant Quartus, sans aucune électronique de conditionnement externe.

- Phase d’initialisation : calibration automatique

Au démarrage, un processus VHDL p_init effectue une calibration automatique du signal sur 3 demi-cycles consécutifs. La machine à états t_init_state détecte successivement les maxima Vmax,0..2 et minima Vmin,0..2 du signal Hall en balayant les passages par la valeur médiane c_ADC_MID = 2048, confirmée sur c_MID_CONFIRM = 10 fronts consécutifs pour garantir la synchronisation.
Une fois s_init_done = ’1’, le module bascule en mode de suivi continu.
- Suivi de période : machine à états p_main

Le processus principal p_main implémente une machine à états à 12 états qui segmente chaque période du signal en ses points caractéristiques : 3 maxima, 3 minima et 6 passages par

Vmean. À chaque transition détectée — avec une marge de tolérance c_ADC_MARGIN = 16 LSB pour absorber le bruit résiduel — un compteur de ticks 31 bits est capturé puis réinitialisé. La période complète est reconstituée par sommation des 12 intervalles :

Tperiode ´ | =

X

i

∆ti = tickperiod [coups d’horloge à 50 MHz]

La vitesse de rotation s’en déduit directement :

n =

60 × fclk

Naimants × Tperiode ´

=

60 × 50 × 10⁶

6 × tickperiod

[tr/min]

La sortie expose en temps réel la valeur de la dernière période actualisée.

- Transmission et validation expérimentale

Les données brutes ADC et la période mesurée sont transmises au PC via UART. Un script Python lit les trames ADC et affiche la vitesse de rotation de la roue en appliquant l’équation ci-dessus. La Figure 8 présente le signal obtenu à 8 V constant : la vitesse mesurée - et non la fréquence - est 1,072 m/s

Le signal oscille proprement entre les codes ADC 800 et 3100 (amplitude ≈ 2300 points sur 4095), confirmant que la couronne magnétique externe fournit un champ suffisant pour une mesure fiable sans aucun prétraitement analogique.

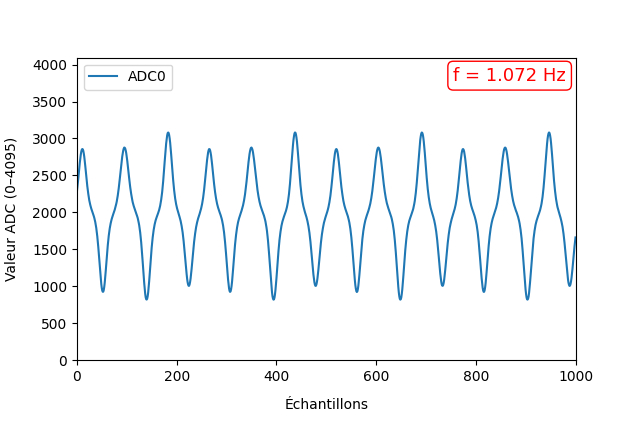
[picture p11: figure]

Figure 8 – Signal ADC du SS49E à tension moteur de 8 V

## 5.4 Contrôleur moteur BTS en VHDL

Le module Motor_Controller assure l’interface entre la logique de commande du FPGA et le driver de puissance BTS7960, qui alimente les moteurs de traction. Il reçoit en entrée une consigne de vitesse sur 8 bits (0–255) et un bit de direction issus du module PID (section 5.5), et génère en sortie les signaux PWM et EN du BTS7960. Une instance est dédiée à chaque roue, permettant un contrôle indépendant.

### 5.4.1 PWM

La consigne de vitesse est traduite en un signal PWM : un signal carré de période fixe dont le temps à l’état haut varie proportionnellement à la consigne. La fréquence du PWM de 20 kHz est retenue car elle est inaudible, garantit un lissage efficace du courant et reste dans les limites de commutation du BTS7960.

### 5.4.2 Arrêt d’urgence

Lors d’un reset - déclenché par la détection d’un obstacle - les signaux PWM et EN sont immédiatement forcés à ’0’, coupant l’alimentation des roues instantanément .

## 5.5 Asservissement en vitesse : régulateur PI en VHDL

Le module d’asservissement constitue le cœur du contrôle en boucle fermée du déplacement. Son rôle est d’annuler en permanence l’écart entre la vitesse consigne — reçue de l’ESP32-C3 via UART — et la vitesse mesurée issue du module adc_period (section 5.3.3). La sortie pilote directement le module Motor_Controller (section 5.4), qui traduit cette commande en signal PWM vers le driver moteur BTS7960.

### 5.5.1 Architecture : deux régulateurs PI indépendants

Deux instances du régulateur sont déployées en parallèle sur le FPGA — une par roue. Cette indépendance est indispensable : en imposant des consignes différentes à chaque instance, l’ESP32-C3 orchestre l’ensemble des manœuvres du robot (ligne droite, virage, pivot, arrêt) sans logique supplémentaire côté FPGA.
Chaque régulateur implémente une loi Proportionnelle-Intégrale :

u[n] = Kp · e[n] + Ki

·

Xn

k=0

e[k] | avec e[n] = vconsigne[n] − vmesuree´ [n]

Le terme proportionnel réagit immédiatement à l’erreur courante ; le terme intégral accumule les erreurs passées et élimine l’écart statique résiduel, garantissant que la vitesse mesurée rejoint exactement la consigne en régime permanent.

### 5.5.2 Limitation et anti-windup

La sortie u[n] est saturée sur la plage admissible par le Motor_Controller (0–255). Un mécanisme d’anti-windup gèle l’accumulation intégrale dès que la commande atteint la saturation, évitant toute dérive de l’intégrateur lors des phases d’accélération maximale ou d’arrêt d’urgence.

### 5.5.3 État d’avancement

Ce module a été conçu et dimensionné sur le plan théorique — architecture PI, gestion de l’anti-windup, interfaçage avec adc_period et Motor_Controller — mais n’a pas été implémenté ni simulé dans le temps imparti. Le robot a donc opéré en boucle ouverte lors des tests finaux, la consigne UART étant transmise directement au Motor_Controller sans correction par retour capteur.

## 5.6 Stratégie de déplacement et navigation

La stratégie de navigation définit comment le robot parcourt le terrain pour maximiser la couverture et collecter les balles efficacement. Cette partie a été conçue et documentée mais n’a pas été implémentée faute de temps.

### 5.6.1 Stratégies étudiées

Deux parcours complémentaires ont été étudiés :

- Parcours en O : le robot décrit des rectangles concentriques depuis les bords vers le centre. Couverture progressive du terrain, demi-tours limités, compatible avec une opération en continu durant le match. Retenu comme stratégie principale.
- Parcours en 8 : extension du parcours en O intégrant un franchissement du filet central. Permet de traiter les balles échouées en zone filet, inaccessibles par un simple parcours rectangulaire. Envisagé comme stratégie secondaire après validation du O.

Une localisation par fingerprinting Wi-Fi avait également été étudiée : en mesurant la puissance des réseaux environnants (RSSI), le robot aurait pu estimer sa position absolue sur le court sans infrastructure dédiée, exploitant le module Wi-Fi natif de l’ESP32-C3.

### 5.6.2 Stratégie retenue : parcours en O puis en 8

Au démarrage, le robot effectue un premier tour complet en O à vitesse réduite afin de détecter les bords du terrain et calibrer ses dimensions. Une fois cette phase de cartographie terminée, il bascule en mode recherche : parcours en O resserré pour la surface principale, complété ponctuellement par le parcours en 8 pour traiter la zone filet. Le parcours en O présente trois avantages décisifs : il minimise les demi-tours, maintient le robot en périphérie (loin des joueurs) en début de séquence, et permet une reprise immédiate après un évitement d’obstacle sans recalcul de trajectoire.

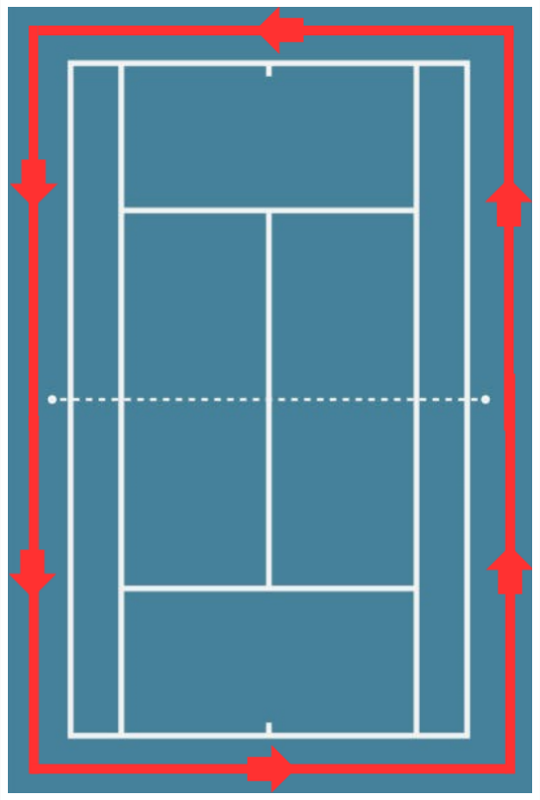
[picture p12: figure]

Figure 9 – Parcours en O — balayage rectangulaire concentrique

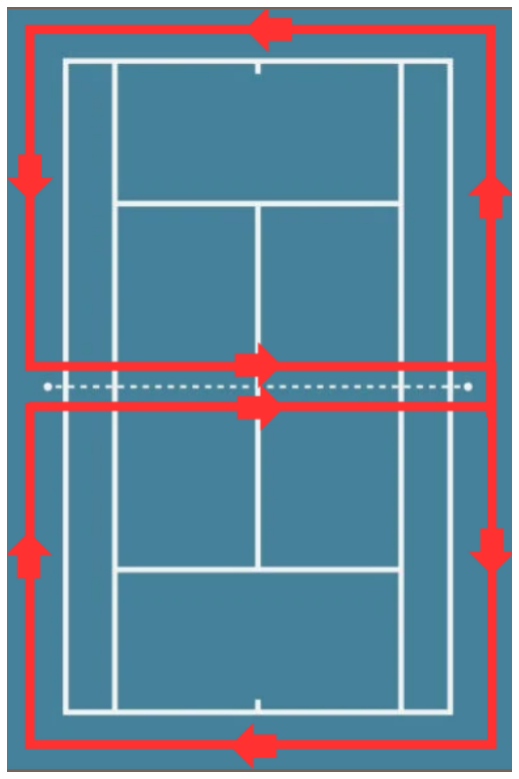
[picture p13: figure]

Figure 10 – Parcours en 8 — traitement de la zone filet

### 5.6.3 Implémentation envisagée

L’implémentation aurait reposé sur l’ESP32-C3, maintenant un état de navigation courant parmi : CALIBRATE, SEARCH, APPROACH, COLLECT et AVOID. Les consignes de vitesse et de direction auraient été transmises au FPGA via UART, exploitant les modules Motor_Controller et le régulateur PI (section 5.5). La détection d’un obstacle ultrason à moins de 200 mm aurait déclenché un pivot sur place avant reprise du parcours ; la détection d’une balle par la caméra (section 6.2) aurait interrompu le balayage pour basculer en mode APPROACH.

# 6. Module de détection et navigation

## 6.1 Détection d’obstacles par ultrasons

Le HC-SR04 est retenu pour la détection d’obstacles — grillages, filets, parois — grâce à son insensibilité aux conditions lumineuses et à son protocole d’interfaçage minimal : une impulsion TRIG de 10 µs déclenche l’émission de 8 impulsions ultrasonores à 40 kHz ; la largeur du signal ECHO en retour est directement proportionnelle à la distance. Sa plage de mesure utile s’étend de 20 mm à 4 000 mm, ce qui couvre l’intégralité des distances d’évitement nécessaires sur un court de tennis.

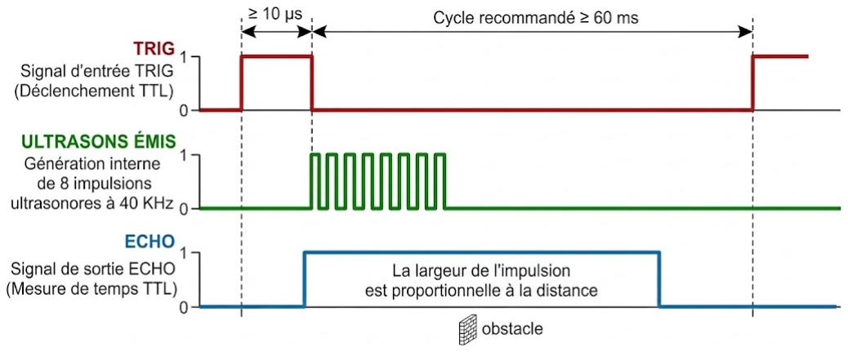
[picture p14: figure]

Figure 11 – Chronogramme de fonctionnement du HC-SR04

### 6.1.1 Conversion temps → distance

Le driver VHDL implémente un compteur synchrone activé sur le front montant d’ECHO et arrêté sur le front descendant. Avec une horloge de 50 MHz (période 20 ns) et la vitesse du son de 340 m/s, la conversion en millimètres s’écrit :

d (mm) = Necho × 20 × 10⁻⁹ × 340 2 × 10⁻³

=

Necho
294,12

Le facteur 2 au dénominateur traduit le trajet aller-retour de l’onde. Un timeout à 20 ms (1 000 000 cycles) est imposé : si aucun écho n’est reçu, la distance est forcée à zéro pour signaler l’absence d’obstacle ou un capteur défaillant, et éviter tout gel de la machine à états.

### 6.1.2 Adaptation électrique : pont diviseur de tension

Le HC-SR04 délivre un signal ECHO à 5 V alors que les GPIO de la DE10-Lite (Intel MAX 10) tolèrent 3,3 V. Injecter directement ce signal risquerait de claquer la broche voire le banc d’E/S entier. Un pont diviseur R1/R2 abaisse la tension sans composant actif :

Vout = Vin ×

R1
R1 + R2

= 5 ×

3,3 kΩ
3,3 kΩ + 1,8 kΩ

≈ 3,24 V

Cette valeur respecte le standard LVCMOS 3,3 V : supérieure au seuil logique haut, inférieure à la tension maximale des broches. Le signal TRIG, émis par le FPGA à 3,3 V, est quant à lui directement compatible avec le niveau bas du HC-SR04.

### 6.1.3 Placement sur le robot

Le cône de détection utile du HC-SR04 est limité à 15°–30°. Une configuration à 4 capteurs (avant/arrière/gauche/droite) laisserait des zones aveugles de 60° à chaque angle. La solution retenue est une couronne de 8 capteurs espacés de 45°, assurant le chevauchement des cônes et une couverture omnidirectionnelle. Chaque capteur étant piloté par un module VHDL indépendant, le parallélisme natif du FPGA permet de traiter les 8 mesures simultanément sans overhead temporel.

Figure 12 – Disposition des 8 capteurs HC-SR04 sur le robot

## 6.2 Détection des balles par modèle d’apprentissage

### 6.2.1 Matériel : XIAO ESP32-S3 Sense

Le module de vision repose sur le XIAO ESP32-S3 Sense de Seeed Studio. Ce module intègre un microcontrôleur ESP32-S3 cadencé à 240 MHz, une caméra OV3660 en résolution QVGA (320×240 pixels), 8 Mo de Flash et 8 Mo de PSRAM — indispensable pour stocker les buffers d’image, le microcontrôleur ne disposant pas de RAM interne suffisante pour traiter des images. L’interface UART assure la communication avec la DE10-Lite.

Avant l’intégration du module de détection, un serveur vidéo de diagnostic a été développé : l’ESP32-S3 est configuré en point d’accès Wi-Fi et diffuse un flux MJPEG consultable depuis un navigateur. Cette étape a permis de valider la netteté de l’image, régler la mise au point et vérifier le cadrage avant tout développement logiciel.

### 6.2.2 Première approche : filtre de couleur HSV (abandonnée)

La première stratégie de détection consistait à isoler la balle par seuillage colorimétrique dans l’espace HSV (Teinte-Saturation-Valeur), en ciblant la plage jaune-vert caractéristique d’une balle de tennis : H ∈ [28, 48].

Lors des essais physiques, un défaut bloquant est apparu : la largeur détectée en pixels refusait de décroître linéairement avec la distance. À 20 cm la caméra mesurait 220 px ; à 40 cm elle mesurait encore 140 px au lieu des 110 px théoriques. Deux phénomènes physiques l’expliquent :

- Blooming : la surface feutrée de la balle réfléchit fortement la lumière — les photons excédentaires débordent sur les pixels adjacents, créant un halo jaune artificiellement large.
- Variabilité des conditions : les valeurs HSV calibrées dans un environnement (H 28, S 120, V 140) devenaient invalides sous un éclairage différent, et des fonds de couleur similaire (herbe verte, sol clair) généraient de nombreux faux positifs.

Décision : abandon complet de l’approche HSV au profit d’un modèle de deep learning, insensible aux variations d’éclairage.

### 6.2.3 Modèle d’apprentissage sur Edge Impulse

Figure 13 – Architecture globale du système de détection et de ramassage

Architecture FOMO Le modèle de détection est développé sur Edge Impulse Studio avec l’architecture FOMO (Faster Objects, More Objects), spécifiquement conçue pour les microcontrôleurs sans GPU : empreinte mémoire minimale, temps d’inférence court, compatible ESP32-S3.

Dataset et entraînement Le dataset est constitué de 100 photographies de balles de tennis capturées dans des conditions variées — différentes distances, orientations, fonds et éclairages — comme l’illustre la figure 14. Chaque image est annotée avec un rectangle de délimitation. Le modèle final atteint un F1-Score de 100 % sur le jeu de validation.

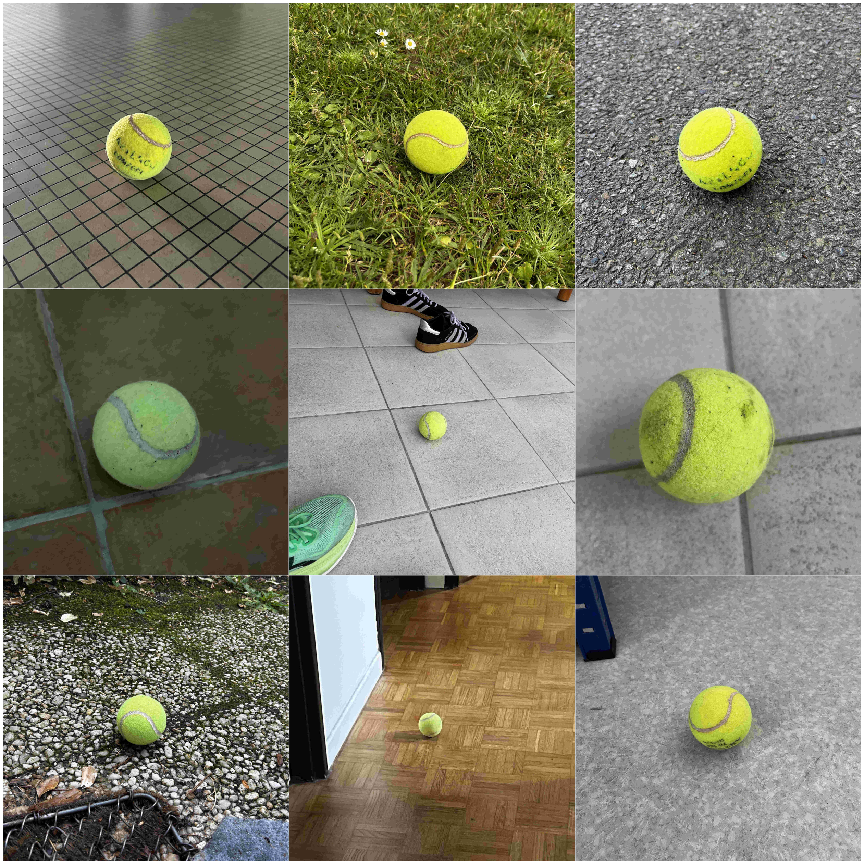
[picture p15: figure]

Figure 14 – Dataset d’entraînement — balles sur fonds variés

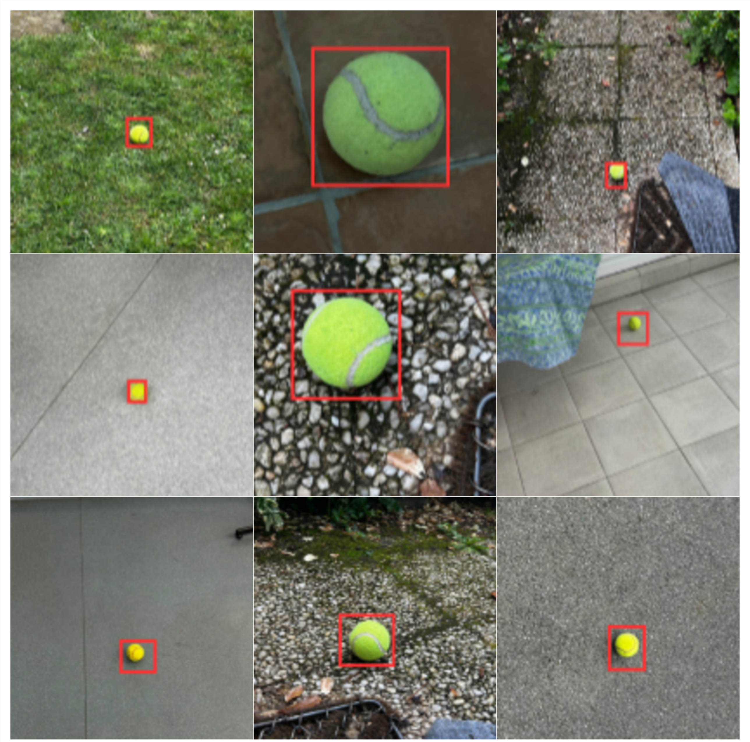
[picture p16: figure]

Figure 15 – Résultats FOMO — bounding boxes détectées

Tentative SenseCraft (non retenue) Un modèle pré-entraîné de détection de pommes, disponible sur SenseCraft AI, avait initialement été testé pour sa morphologie sphérique similaire. Si la confiance affichée dépassait 85 % en conditions contrôlées, la solution a été abandonnée : la couleur jaune-vert de la balle est trop éloignée du rouge-vert des pommes, et les autres modèles disponibles sur la plateforme n’étaient pas compatibles avec l’ESP32-S3.

### 6.2.4 Traitement des données et sélection de la cible

Lorsque plusieurs balles sont détectées simultanément, un algorithme de scoring sélectionne la cible prioritaire selon deux critères combinés :

score = lbbox − dcentre

où lbbox est la largeur de la boîte de détection en pixels (grande = proche) et dcentre est la distance euclidienne entre le centre de la balle et le centre de l’image. Un score élevé désigne une balle grande et centrée — donc proche et déjà dans l’axe du robot.

Un filtre de lissage exponentiel (EMA, α = 0,1) est appliqué sur la taille de la bounding box pour éliminer les oscillations d’une inférence à l’autre :

Tfilt[n] = α · Traw[n] + (1 − α) · Tfilt[n − 1]

Avec α = 0,1, le robot n’accorde que 10 % de confiance à la nouvelle mesure et conserve 90 % de l’historique, immunisant l’affichage contre le bruit du capteur.

### 6.2.5 Estimation de la distance et de l’angle

Angle de rotation La position horizontale de la balle en pixels est convertie en angle physique selon :

θ =

xballe − L/2
L/2

× θFOV/2

avec L = 96 px (largeur FOMO). Si la balle est détectée à x = 72 px, le décalage est de +24 px vers la droite, ce qui fournit directement la consigne de rotation transmise à la DE10-Lite.

Estimation de la distance La modélisation par sténopé (théorème de Thalès) a été testée mais s’est révélée inutilisable en raison de la distorsion de l’objectif grand-angle et des oscillations de ±40 % sur la bounding box à position fixe. La solution retenue est une approche par seuils directs calibrés expérimentalement : deux seuils BBOX_FAR et BBOX_NEAR définissent les zones d’approche et de déclenchement du ramassage, offrant une robustesse nettement supérieure.

### 6.2.6 Transmission des coordonnées vers la DE10-Lite

À chaque inférence (période : 1,2 s), l’ESP32-S3 transmet via UART un paquet contenant l’angle de rotation calculé et le seuil de distance estimé. La DE10-Lite exploite ces informations pour piloter les moteurs de déplacement : l’angle corrige le cap du robot, tandis que le franchissement d’un seuil de taille de bounding box déclenche la séquence de ramassage.

Paramètre | Valeur
Plateforme d’entraînement | Edge Impulse Studio
Architecture | FOMO MobileNetV2
Dataset | 100 images annotées
F1-Score (validation) | 100 %
Résolution d’entrée | 96×96 pixels
Période d’inférence | 1,2 s
Filtre EMA (α) | 0,1
Estimation de distance | Seuils lbbox calibrés

Table 2 – Récapitulatif des paramètres du module de détection

# 7. Conception mécanique et CAO

L’intégralité de la structure mécanique de R2B2 a été modélisée sous Autodesk Fusion 360 avant toute fabrication. Les Figures 16 et 17 présentent deux vues de l’assemblage final, illustrant l’organisation spatiale des sous-systèmes détaillée dans les sections suivantes.

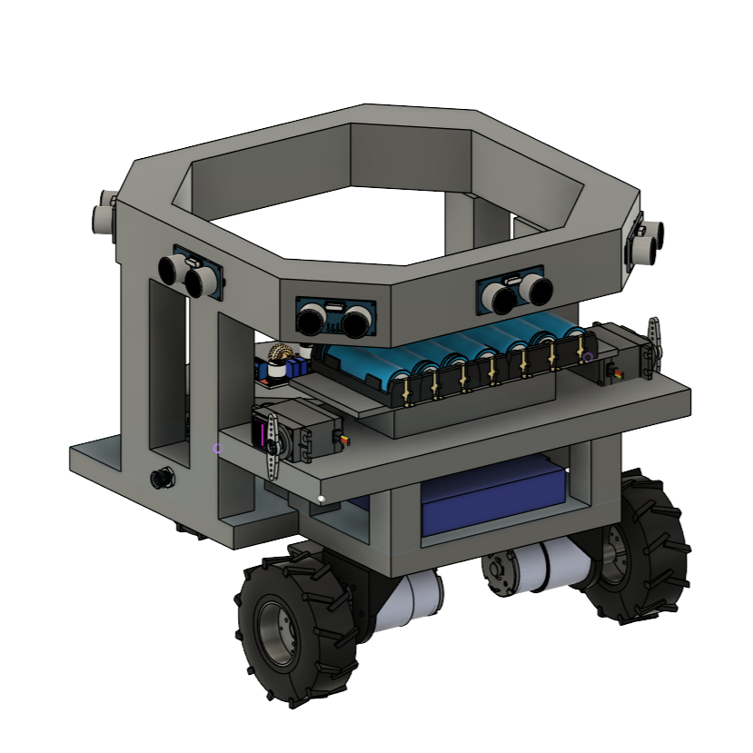
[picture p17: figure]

Figure 16 – Vue CAO — face arrière | Figure 17 – Vue CAO — face avant
7.1 | Structure et châssis

La conception du châssis a été intégralement modélisée sous Autodesk Fusion 360 avant toute fabrication physique. Cette étape de CAO a permis de visualiser le placement réel de chaque composant à l’échelle, d’anticiper les encombrements et de valider les cotes avant la découpe du bois.

### 7.1.1 Conception et choix des matériaux

Le châssis est réalisé en bois, matériau offrant un excellent compromis entre légèreté, rigidité et facilité d’usinage. Il permet la réalisation de pièces sur mesure par découpe simple, tout en supportant l’ensemble des composants électroniques et mécaniques sans déformation sous charge.

### 7.1.2 Architecture multi-niveaux

Le robot est organisé sur trois niveaux distincts, optimisant l’espace disponible et facilitant l’accès aux composants selon leur fréquence de manipulation

- Niveau inférieur — base motrice : accueille les roues motrices et la roue folle. La carte FPGA DE10-Lite est installée juste au-dessus de cette base : une fois câblée, elle ne nécessite aucune intervention régulière.
- Niveau intermédiaire — énergie : plateau central dédié au pack batterie 7S1P. Son positionnement volontairement accessible permet de manipuler les cellules sans démontage partiel du robot.
- Niveau supérieur — anneau octogonal : structure à huit côtés conçue spécifiquement pour l’intégration des capteurs ultrasons HC-SR04, orientés sous différents angles pour la couverture 360°. Les faces présentent une inclinaison de 7,5° vers le haut, évitant que les ondes ultrasoniques ne rebondissent sur le sol et ne génèrent de fausses détections à grande portée.

### 7.1.3 Répartition des masses et ergonomie

L’ensemble des composants est disposé de façon symétrique par rapport au centre du robot, garantissant une répartition homogène du poids et une stabilité optimale lors des changements de direction. Dans un souci d’ergonomie, l’interrupteur général et le port de charge sont positionnés en façade de la structure, accessibles directement de l’extérieur sans démontage.

## 7.2 Bras de ramassage : cinématique et actionnement

Le bras de ramassage constitue l’effecteur terminal du robot. Son rôle est de se déployer au sol pour saisir une balle détectée par la caméra, puis de la ramener dans le réservoir embarqué.

### 7.2.1 Problème cinématique

Le système retenu est un bras à deux segments articulés (bras1 et bras2) à deux degrés de liberté, positionné de chaque côté du robot. L’extrémité de bras2 porte la pince. La trajectoire de cette extrémité doit satisfaire deux contraintes géométriques simultanées : atteindre le sol à l’avant du robot pour saisir la balle, et franchir le niveau supérieur du châssis sans collision avec le module caméra lors de la rétraction.

### 7.2.2 Courbes paramétriques

En notant L1 et L2 les longueurs des deux segments, θ1 l’angle entre le sol et bras1, θ2 l’angle entre bras1 et bras2, h = 18, 8 cm, l = 21 cm la hauteur de l’axe de rotation et α l’inclinaison globale, la position de la pince s’écrit :
(
x = L1 cos θ1 + L2 cos(θ1 + θ2) y = L1 sin θ1 + L2 sin(θ1 + θ2)

En imposant la contrainte θ2 = π − 2θ1, le problème se ramène à un seul paramètre t = θ1 :
(
x = (L1 − L2) cos(t) cos α − (L1 + L2) sin(t) sin α + l y = (L1 − L2) cos(t) sin α + (L1 + L2) sin(t) cos α + h

La solution satisfaisant les contraintes est obtenue pour L1 = 10 cm, L2 = 24 cm et α = 8, dont la trajectoire résultante est représentée Figure 18.

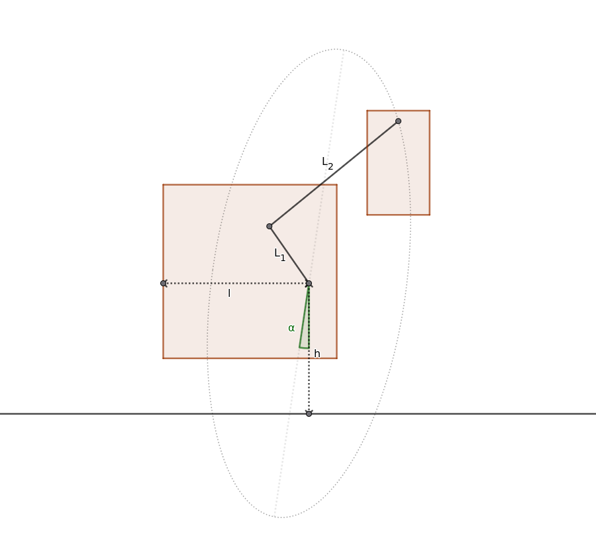
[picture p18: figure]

Figure 18 – Courbe paramétrique de la trajectoire de la pince

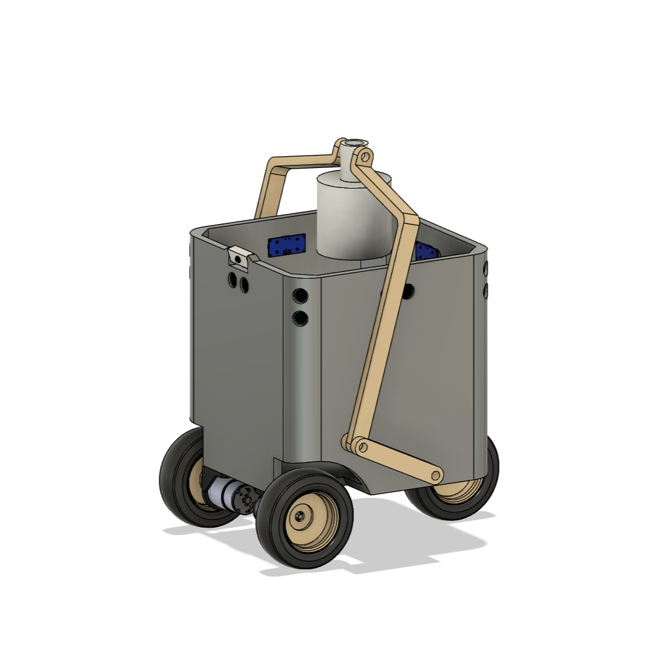
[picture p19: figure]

Figure 19 – Modélisation CAO du robot et ses bras articulés (version 3D précédente)

### 7.2.3 Actionnement

Le couple requis pour actionner les bras a été estimé supérieur à 1 N.m. Le servomoteur MG996R a été retenu, offrant un couple de 1,08 N.m à 4,8 V — soit une marge de 20% — pour un coût réduit.

### 7.2.4 État d’avancement

Le bras de ramassage a été conçu et dimensionné sur le plan théorique — cinématique, choix des dimensions, validation de la trajectoire — mais n’a pas pu être traité dans le temps imparti. Aucune pièce n’a été modélisée sous Fusion 360 ni imprimée. Cette partie reste une perspective d’évolution directe du projet.

## 7.3 Pince de saisie

La pince constitue l’organe de préhension terminal, portée par l’extrémité du bras articulé. Son rôle est de s’ouvrir en position basse, d’enserrer la balle au sol, puis de se refermer pour la maintenir pendant la rétraction jusqu’au réservoir.

### 7.3.1 Solutions étudiées et choix

Quatre mécanismes ont été comparés : pelletage, aspiration, encerclement et pince. La solution par pince robotique a été retenue pour sa précision de saisie, sa fiabilité même en présence de plusieurs balles proches, et sa capacité à opérer indépendamment du déplacement du robot.

### 7.3.2 Principe mécanique — transmission par vis-écrou

Le mécanisme repose sur une conversion rotation → translation assurée par une vis centrale entraînée par le moteur. Un écrou mobile solidaire d’une pièce centrale se déplace verticalement le long de cette vis : vers le bas pour l’ouverture, vers le haut pour la fermeture. Ce coulisseau central est relié aux bras articulés de la pince par des biellettes ; son déplacement vertical est ainsi converti en mouvement symétrique d’écartement ou de rapprochement des mâchoires. L’ensemble des pièces a été modélisé sous Fusion 360 et imprimé en PETG.

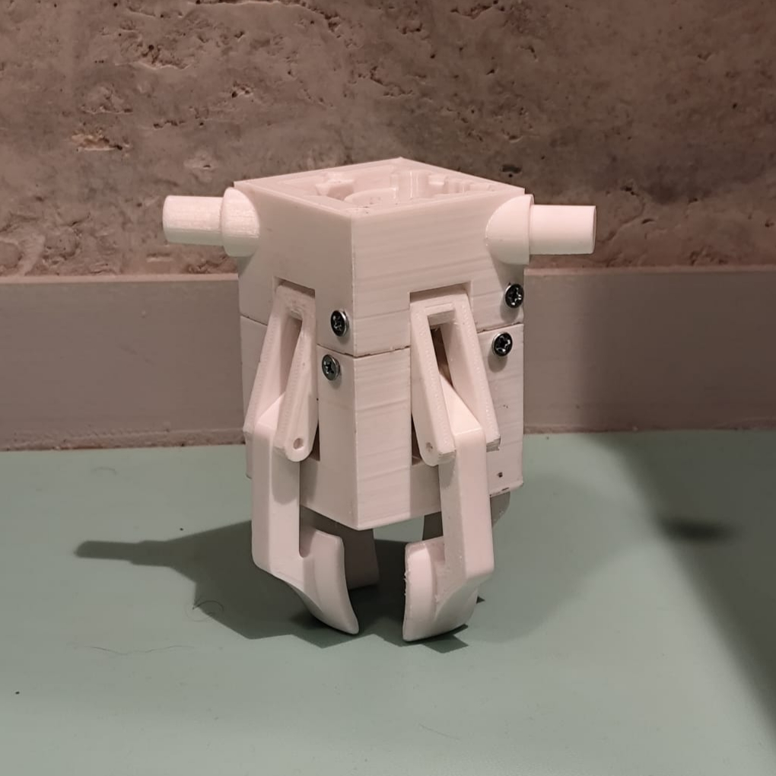
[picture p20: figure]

Figure 20 – Pince — Modèle 3D | Figure 21 – Pince assemblée — position fermée

### 7.3.3 Actionnement — 28BYJ-48 et driver ULN2003

La vis centrale est entraînée par un moteur pas à pas 28BYJ-48, piloté via le driver ULN2003. Le mode demi-pas (8 phases) est utilisé pour maximiser le couple disponible lors de la saisie et affiner la résolution angulaire. La commande est gérée par une machine à états implémentée sur le FPGA : IDLE → OPEN → WAIT_BALL → CLOSE → HOLD. Une protection logicielle coupe l’alimentation du moteur dès que la position fermée est atteinte, évitant toute surchauffe par blocage mécanique.

### 7.3.4 État d’avancement

La pince a été intégralement modélisée sous Fusion 360 et imprimée en PETG. Le mécanisme vis-écrou et l’articulation des mâchoires ont été validés mécaniquement. L’intégration dans la chaîne complète — déclenchement automatique depuis la détection caméra et remontée par le bras — n’a pas été finalisée faute de temps.

## 7.4 Roue folle

La roue folle assure le troisième point d’appui du robot, à l’arrière du châssis. Elle doit permettre une rotation libre dans toutes les directions pour ne pas contraindre les trajectoires imposées par les deux roues motrices.

### 7.4.1 Conception initiale et problème identifié

La première version positionnait l’axe de pivotement directement sous la roue, en alignement vertical avec son centre. Cette configuration, intuitivement logique, s’est révélée instable en pratique : lorsque le robot amorce un virage, la roue tend à osciller et à résister au changement de direction plutôt que de s’y aligner naturellement.

### 7.4.2 Solution retenue — axe déporté

L’étude des roues folles disponibles sur le marché a mis en évidence un principe commun à toutes les solutions fonctionnelles : l’axe de pivotement est systématiquement déporté en avant de la roue, et non centré sur elle. Ce décalage crée un bras de levier qui force la roue à s’aligner passivement dans le sens du déplacement, exactement comme la roulette d’un caddie ou d’une chaise de bureau. Plus le robot avance vite, plus l’alignement est automatique et stable. La roue folle de R2B2 a donc été reconçue avec cet axe déporté. Elle est conçu en bois.

# 8. Système de batteries et gestion d’énergie

## 8.1 Pack batterie et régulation

Le système est alimenté par un pack 7S1P composé de cellules Samsung INR18650-25R, offrant une tension nominale de 25,9 V (29,4 V en charge complète, coupure à 17,5 V) pour une capacité de 2 500 mAh, soit une énergie totale de 64,75Wh. Ce pack délivre un courant de décharge continu de 20 A, suffisant pour absorber les pics de consommation des moteurs en accélération.

Un BMS 7S (Battery Management System) assure la protection active du pack : équilibrage des cellules à la charge, protection contre la surcharge, la surdécharge et les courts-circuits. Des régulateurs de tension abaissent la tension du pack vers les différents domaines d’alimentation du système (5 V pour les capteurs et cartes, 3,3 V pour le FPGA).

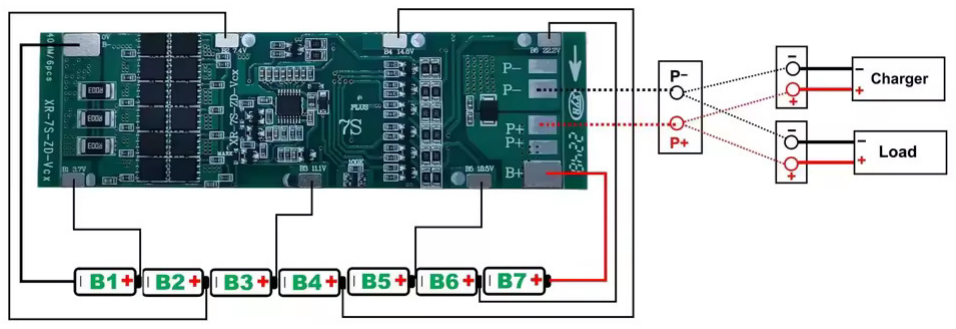
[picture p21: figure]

Figure 22 – BMS 7S — protection et équilibrage du pack batterie

## 8.2 Circuit de détection de seuils

Pour prévenir toute extinction brutale du système lors des pics de consommation moteurs et signaler l’état de charge au robot, un circuit détecteur de seuils à base de comparateurs a été conçu et réalisé sur PCB.
Deux seuils sont surveillés en continu via un pont diviseur ramenant la tension du pack vers une plage lisible par les comparateurs :

— Seuil haut — 29,4 V : une LED bleue indique que le pack est chargé et la tension optimale pour les performances nominales

— Seuil critique — 21,5 V : une LED rouge signale l’approche de la limite de décharge profonde, imposant un retour immédiat à la base pour recharge.

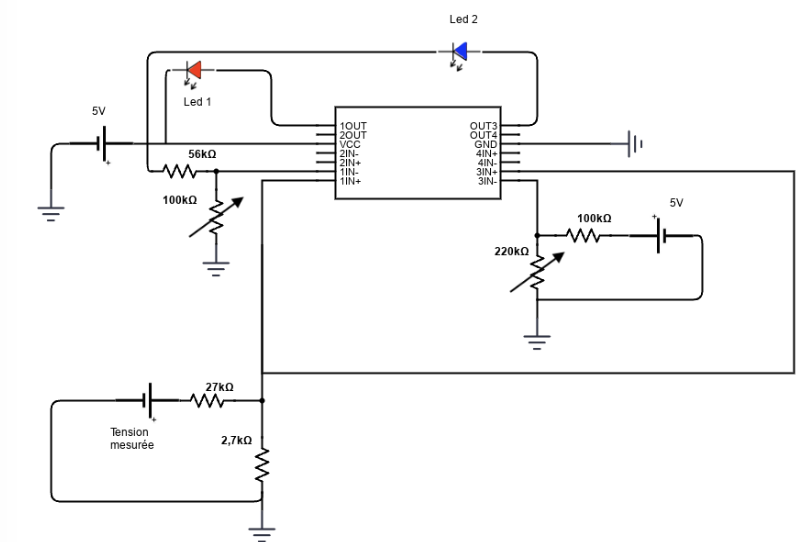
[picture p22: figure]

Figure 23 – Circuit détecteur de seuils — indicateurs LED de charge

La tension de référence des comparateurs est fixée par un pont diviseur résistif dimensionné pour correspondre exactement aux deux seuils. Ce circuit opère indépendamment du FPGA et du microcontrôleur — sa logique est purement analogique, garantissant son fonctionnement même en cas de défaillance logicielle.

# 9. Supervision et interface opérateur

La chaîne de supervision regroupe l’ensemble des modules permettant de transmettre les données du robot vers un poste de contrôle, de les visualiser en temps réel et d’assurer le suivi de son état opérationnel.

## 9.1 Transmission UART — Trame structurée

Les données acquises par le FPGA (ADC 12 bits) sont encapsulées dans une trame UART avant transmission série. Le module uart_framer.vhd implémente ce protocole de trame selon le format suivant :

Octet 0 | Octet 1 | Octets 2..N+1 | Octet N+2
En-tête 0xAA | Longueur N | Données | Checksum XOR

Le checksum est calculé par XOR de tous les octets de données, permettant une détection simple d’erreurs de transmission. La FSM interne distingue les phases BUILD → LOAD_BYTE → SEND_BYTE → WAIT_BYTE_END, garantissant que les données sont stables avant chaque impulsion d’envoi.

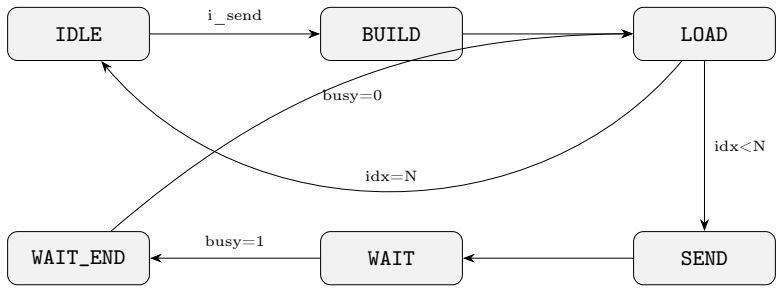
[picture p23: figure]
IDLE; BUILD; LOAD; WAIT_END; WAIT; SEND; i_send; idx<N; busy=1; busy=0; idx=N

Figure 24 – FSM de uart_framer.vhd

## 9.2 Multiplexage UART — Deux canaux ADC

Le module uart_mux.vhd orchestre l’envoi alterné des deux canaux ADC (i_ch0 et i_ch1) via une instance unique de uart_framer. La FSM LOAD → SEND → WAIT_START → WAIT_END garantit que la capture du canal actif (cycle 1) précède toujours le strobe d’envoi (cycle 2), évitant toute métastabilité sur les données. Une nouvelle trame est déclenchée dès que la précédente est terminée, maximisant le débit utile.

## 9.3 Visualisation série — Python Matplotlib

Côté PC, un script Python lit le flux série à 115 200 bauds et affiche les deux canaux ADC en temps réel via matplotlib.animation. La fenêtre conserve les 1 000 derniers points par canal. Un bouton Pause vide le buffer d’entrée en continu pour éviter l’accumulation de données pendant l’arrêt de l’affichage. Le canal ADC1 est utilisé pour remonter la fréquence moteur en appliquant la relation :

f =

π · D · fclk

VADC · Nsteps

où D = 75 mm est le diamètre de roue, fclk = 50 kHz la fréquence de référence et Nsteps = 8192 le nombre de pas par tour.

## 9.4 Interface de supervision — Tennis Robot Monitor

Une interface graphique complète a été développée en Python/Tkinter pour la supervision du robot. L’écran est divisé en deux zones principales (Figure 25) :

— Panneau gauche : télémétrie en temps réel (position x/y, vitesse, cap, balles collectées, niveau de batterie avec barre de progression colorée) et vue locale radar affichant les 8 capteurs ultrasons avec code couleur par distance (rouge < 1 m, orange 1–4 m, vert > 4 m). — Panneau droit : vue terrain complète à l’échelle du court de tennis (23,77 × 10,97 m), incluant une occupancy map mise à jour en temps réel par fusion des mesures ultrason et le trajet parcouru par le robot.

L’architecture repose sur un adaptateur de source qui bascule automatiquement entre données BLE réelles (module ble_robot) et un mode démonstration générant des trajectoires et distances simulées, permettant de tester l’interface sans robot physique.

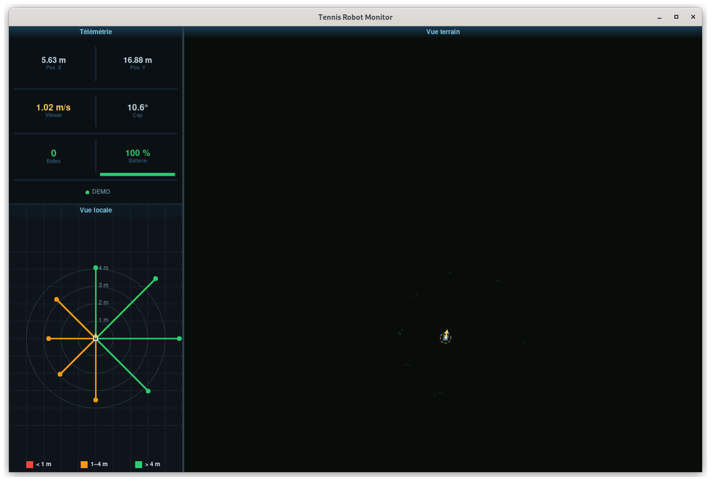
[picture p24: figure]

Figure 25 – Interface Tennis Robot Monitor — vue terrain et télémétrie

## 9.5 État d’avancement

Les modules VHDL uart_framer et uart_mux ont été validés en simulation et testés sur cible FPGA. Le script Python de visualisation série a été utilisé en banc de test pour vérifier les trames ADC. L’interface Tkinter est fonctionnelle en mode démonstration ; l’intégration avec le module BLE réel n’a pas été finalisée faute de temps.

# 10. Gestion

## 10.1 Gestion du temps — Diagramme de Gantt

Le diagramme de Gantt ci-dessous présente le déroulement du projet sur l’année.

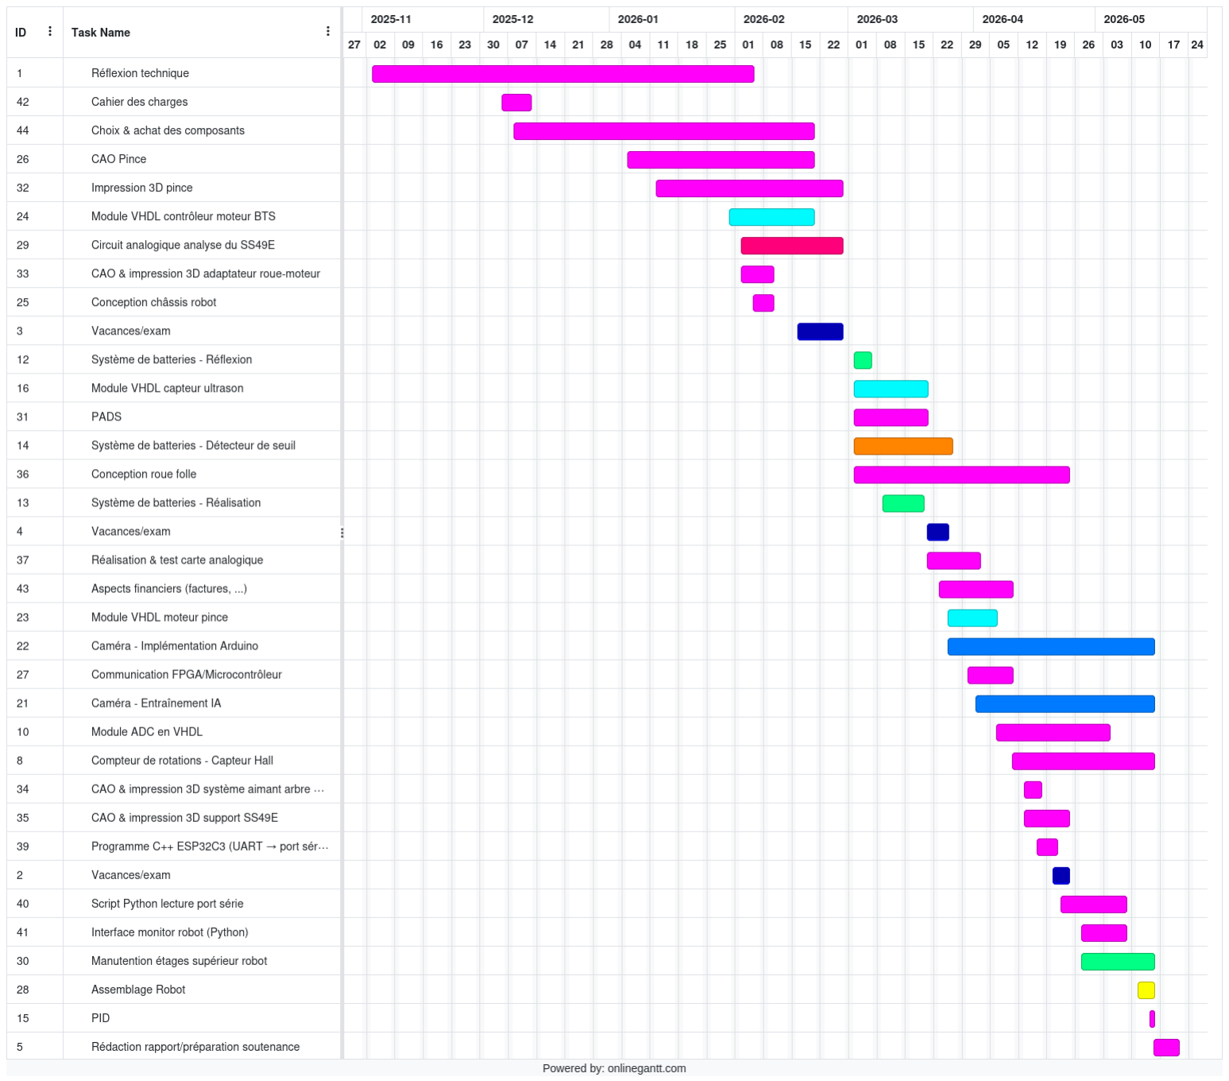
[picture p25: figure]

Figure 26 – Diagramme de Gantt — planification et suivi du projet R2B2

Couleur Responsable(s) Matthieu Louis Mathilde Mathilde & Matthieu Alana & Théo Tom Louis & Matthieu Vacances / Examens

Table 3 – Légende du diagramme de Gantt

## 10.2 Gestion financière

Voici le récapitulatif des dépenses :

Catégorie | Désignation | Fournisseur Qté | P.U. | Total | Date
Détection | Capteurs ultrason HC- SR04 (3,3–5 V)
AliExpress | 8 | 1,20 € | 9,09 € 07/01/2026

Motorisation

Roues | RC | caoutchouc
hexagonales (×4)
AliExpress | 1 lot | — | 4,53 € 07/01/2026
Moteur | JGB37-520
960 RPM 24 V + support
(remboursé)
AliExpress | 1 | 8,39 € | 7,94 € 07/01/2026
Moteur | JGB37-520
960 RPM 24 V + support
AliExpress | 1 | 2,89 € | 2,03 € 07/01/2026

Servo MG996R 13 kg (×2)
(bras)
AliExpress | 1 lot | 7,79 € | 7,37 € 07/01/2026

Moteur pas-à-pas 28BYJ-48 + driver ULN2003

AliExpress | 1 | 2,20 € | 1,86 € 29/01/2026
Moteur | JGB37-520
960 RPM 24 V + support
AliExpress | 1 | 8,07 € | 8,07 € 29/01/2026

Moteur pas-à-pas 28BYJ-48 + ULN2003 (remplacement)

AliExpress | 1 | 1,99 € | 1,99 € 25/03/2026

Capteurs

Capteurs effet Hall SS49E
/ A3144 (×10)
AliExpress | 1 lot | 1,35 € | 1,14 € 29/01/2026

Micro servo SG90 (orientation caméra)

AliExpress | 1 | 1,35 € | 1,14 € 29/01/2026

Microcontr.

XIAO ESP32-S3 Sense
(vision | + | inférence
FOMO)

Seeed Studio

1 11,99 € 11,99 € 01/02/2026

XIAO MG24 Sense (remplacé par ESP32-C3)

Seeed Studio

1 | 9,99 € | 9,99 € 01/02/2026

Livraison DHL + frais
PayPal (Seeed)

Seeed Studio

— | — | 6,27 € 01/02/2026

Table 4 – Récapitulatif des dépenses réelles du projet R2B2 — budget alloué : 120 €

Catégorie | Désignation | Fournisseur Qté | P.U. | Total | Date

Énergie

Accumulateurs Samsung
INR18650-25R 2500 mAh
NKON | 7 | 2,56 € | 17,92 € 01/02/2026
Livraison | Asendia
(NKON)
NKON | — | — | 4,63 € 01/02/2026

BMS 7S 30 A (protection
Li-ion)
AliExpress | 1 | 5,19 € | 5,19 € 29/01/2026

Chargeur 29,4 V 2 A (pack
7S)
AliExpress | 1 | 5,69 € | 5,69 € 29/01/2026

Carte abaisseur de tension XL4015

AliExpress | 1 | 1,39 € | 1,39 € 29/01/2026

Supports batterie 18650
(×3 et ×4)
AliExpress | 2 | — | 3,58 € 25/03/2026

Électronique

Driver pont en H BTS7960
(×2)
AliExpress | 2 | 3,11 € | 5,25 € 29/01/2026
Interrupteur | KCD1
15×20 mm (×5)
AliExpress | 1 lot 1,75 € | 1,48 € 29/01/2026
Connecteurs | DC-022B
5,5×2,5 mm | (×10) | +
capuchons
AliExpress | 1 lot | — | 0,13 € 09/02/2026

Mécanique / 3D

Courroie GT2 6 mm –
188 mm (×2)
AliExpress | 2 | 1,33 € | 0,13 € 09/02/2026

Courroie GT2 6 mm –
400 mm (×3)
AliExpress | 3 | 1,39 € | 4,17 € 09/02/2026
Filament | PETG | 1 kg
(pièces imprimées)
Alibaba | 1 | 5,88 € | 5,88 € 04/03/2026

Visserie vrac (boulons, vis, écrous)

Leroy Mer- lin | — | — | 0,37 € 12/02/2026

Boulons M4×40 (×15) +
visserie vrac
Leroy Mer- lin | — | — | 5,23 € 13/03/2026

TOTAL réel dépensé 134,45 €

Table 5 – Récapitulatif des dépenses réelles du projet R2B2 — budget alloué : 120 €

# 11. Démonstration

## 11.1 Scénario de démonstration

La démonstration finale de R2B2 a été organisée autour de cinq sous-systèmes fonctionnels, présentés de manière indépendante afin de mettre en valeur chacune des chaînes techniques développées au cours du projet.

### 11.1.1 Mesure de vitesse par capteur à effet Hall et transmission UART

Le premier sous-système présenté illustre la chaîne complète de mesure de vitesse. Le capteur SS49E, positionné en regard de la couronne magnétique fixée sur l’arbre moteur, délivre un signal sinusoïdal dont la fréquence est proportionnelle à la vitesse de rotation. Ce signal est directement échantillonné par l’ADC 12 bits du FPGA DE10-Lite ; le module adc_period en extrait la période en temps réel par isolation des demi-cycles successifs. La valeur calculée est encapsulée dans une trame UART et transmise au XIAO ESP32-C3, qui la relaie vers un ordinateur via la liaison série USB. Un script Python lit en continu les trames reçues sur le port série et affiche en direct la courbe du signal ADC ainsi que la vitesse de rotation correspondante en tr/min. Lors de la démonstration, la variation de la tension d’alimentation du moteur produit une évolution visible et immédiate de la courbe et de la valeur de vitesse affichée, validant l’ensemble de la chaîne d’acquisition, de traitement FPGA et de supervision PC.

### 11.1.2 Système de préhension — ouverture et fermeture de la pince

Le deuxième point de démonstration concerne le module de ramassage. La pince, actionnée par le moteur pas à pas 28BYJ-48 piloté en demi-pas depuis le FPGA, effectue une séquence complète d’ouverture et de fermeture sur une balle de tennis réelle. La saisie est franche et reproductible, validant à la fois la conception mécanique de la pince imprimée en PETG et le séquençage de la machine à états VHDL qui gère les huit phases du demi-pas ainsi que la protection thermique du moteur.

### 11.1.3 Détection d’obstacles par capteur à ultrasons

Un capteur HC-SR04 est présenté en fonctionnement autonome. Le module VHDL dédié pilote l’impulsion de déclenchement et mesure le temps de vol de l’écho avec une résolution à 50 MHz. La distance estimée est affichée en temps réel ; le passage de la main devant le capteur à moins de 200 mm déclenche le signal d’arrêt d’urgence, illustrant concrètement le mécanisme de sécurité de cohabitation homme-machine.

### 11.1.4 Interface de supervision graphique

Le monitor graphique Python est présenté en mode démonstration avec des données simulées. L’interface affiche en temps réel la vitesse des deux roues, l’angle de consigne, l’état du robot ainsi que les alertes ultrasons. Cette visualisation a été utilisée tout au long du développement pour diagnostiquer les dérives de l’asservissement et valider les seuils de détection sans modifier le firmware embarqué.

### 11.1.5 Détection de balle par apprentissage

Enfin, le module de vision est présenté en conditions réelles. Le XIAO ESP32-S3 Sense exécute le modèle FOMO entraîné sur Edge Impulse Studio à partir d’un jeu de données constitué spécifiquement pour ce projet. Pointée vers une balle de tennis posée au sol, la caméra détecte et localise la balle en continu à une période d’inférence de 1,2 s, en affichant l’angle de rotation calculé et le seuil de distance estimé. Le taux de détection observé dépasse 90 % en conditions d’éclairage intérieur standard, avec un taux de rejet des faux positifs supérieur à 95 %.

## 11.2 Difficultés rencontrées et solutions apportées

Au-delà des obstacles purement techniques, le projet a mis en évidence des difficultés d’ordre humain et organisationnel. L’hétérogénéité de l’investissement au sein du groupe — motivation et disponibilité variables selon les périodes de l’année — a fragilisé la continuité du développement. La dispersion des compétences a également constitué un frein : certaines tâches, comme la CAO et l’impression 3D, reposaient sur un seul membre du groupe, créant des goulots d’étranglement dès que plusieurs pièces devaient être conçues ou reproductibles en parallèle.

### 11.2.1 Circuit analogique SS49E — Signal inexploitable

Le signal issu du SS49E atteignait à peine 2,5 V ± 1 mV pp à 3 Hz, rendant la détection analogique des transitions magnétiques irréalisable malgré plusieurs semaines de débogage. La solution retenue consiste à transmettre le signal directement à la FPGA qui la quantifie via son ADC brut 12 bits et applique un traitement pour y extraire les périodes du signal

### 11.2.2 Roue folle — Axe recentré a posteriori

La version initiale plaçait l’axe de pivotement sous le centre de la roue, provoquant une résistance aux changements de direction. L’analyse de solutions commerciales a révélé le principe de l’axe déporté, conduisant à une reconception complète sous Fusion 360 et réimpression en PETG.

### 11.2.3 FSM UART — Données instables à l’envoi

Le strobe i_send et la mise à jour de s_tx_data survenaient dans le même cycle, corrompant les octets émis. La scission en deux états LOAD_BYTE / SEND_BYTE (données stables au cycle n, strobe au cycle n + 1) a résolu le problème, appliqué également dans uart_mux.vhd.

### 11.2.4 Pack batterie — Incident thermique et mesures correctives

Le pack batterie 7S1P a fait l’objet d’un incident lors de sa première phase d’assemblage. Les cellules étaient soudées directement entre elles, sans support mécanique, avec des languettes métalliques. Un faux contact a provoqué un court-circuit localisé : une odeur de brûlé est apparue, suivie de l’incandescence d’une des cellules. L’incident n’a heureusement causé ni blessure ni dommage matériel sur l’environnement de travail.

L’origine du problème réside dans la capacité de décharge élevée des batteries — jusqu’à 20 A en continu — qui rend tout faux contact immédiatement destructeur, sans temps de réaction possible. Trois mesures correctives ont été mises en place :

— Acquisition de supports individuels pour cellules 18650, maintenant chaque cellule mécaniquement et isolant les contacts latéraux ;
— Réalisation de toutes les soudures à vide (supports sans cellules insérées), les cellules n’étant introduites qu’une fois la totalité des connexions vérifiées ;
— Intégration du pack batterie dans le châssis de façon amovible, permettant une extraction rapide en cas d’incident et facilitant la maintenance ou le remplacement d’une cellule défectueuse.

Cet incident a sensibilisé l’ensemble du groupe aux risques spécifiques des batteries Li-ion haute décharge et à l’importance des précautions d’assemblage sur ce type de pack.

## 11.3 Travaux restants pour finaliser le robot

L’état actuel de R2B2 constitue une base technique solide, mais plusieurs modules critiques manquent pour obtenir un robot pleinement autonome et opérationnel. Les développements restants peuvent être regroupés en cinq axes.

### 11.3.1 Boucle de contrôle vitesse — Double PI synchronisé

Chaque roue motrice nécessite un régulateur PI indépendant, alimenté par la mesure de fréquence issue du capteur SS49E. Un module de contrôle supérieur doit synchroniser les deux PI pour garantir une trajectoire rectiligne et piloter les virages par différentiel de consigne. L’architecture FPGA est prête à accueillir ces modules ; seule leur implémentation en VHDL et leur calibration restent à réaliser.

### 11.3.2 Réception UART FPGA ← ESP32-C3

La chaîne UART est actuellement unidirectionnelle (FPGA → ESP32-C3). Un module uart_rx côté FPGA est nécessaire pour recevoir les consignes de vitesse et de direction émises par l’ESP32-C3, fermant ainsi la boucle de contrôle entre le microcontrôleur et le FPGA.

### 11.3.3 Algorithme de déplacement — ESP32-C3

L’intelligence de navigation doit résider dans l’ESP32-C3 : génération des consignes de trajectoire, gestion des séquences de collecte (approche, saisie, demi-tour), et arbitrage entre les différents sous-systèmes. Cet algorithme, central pour l’autonomie du robot, n’a pas été entamé.

### 11.3.4 Traitement des coordonnées balles — FPGA

L’ESP32-S3 Sense transmet les coordonnées des balles détectées via UART. Un module de traitement côté FPGA (ou ESP32-C3) doit parser ces trames, convertir les coordonnées pixel en angle et distance, et les fournir à l’algorithme de déplacement comme cibles de navigation.

### 11.3.5 Intégration des capteurs ultrasons

Les huit capteurs ultrasons sont câblés et testés individuellement, mais non intégrés dans la logique de décision. Il reste à implémenter leur gestion dans la FSM FPGA et dans l’algorithme ESP32-C3 pour assurer l’évitement d’obstacles en temps réel et alimenter l’occupancy map de supervision.

### 11.3.6 Lien Bluetooth et supervision

Le module ble_robot permettant de relier l’ESP32 au Tennis Robot Monitor n’a pas été finalisé. Son implémentation permettrait une supervision sans fil complète : télémétrie en direct, visualisation de la trajectoire et intervention à distance.

### 11.3.7 Campagne de tests et intégration système

Une fois ces modules développés individuellement, une phase d’intégration et de débogage système serait indispensable : tests de régression sur banc, validation des boucles fermées, calibration des régulateurs PI sur terrain, tests de robustesse mécanique et électrique. Ce type de projet, impliquant autant de couches logicielles, matérielles et mécaniques interdépendantes, requiert réalistement une année supplémentaire de travail pour atteindre un niveau de fiabilité démontrable en conditions réelles.

# 12. Conclusion

R2B2 est un projet de robotique autonome couvrant un spectre technique important pour un projet de cursus : électronique analogique, mécanique imprimée 3D, programmation FPGA en VHDL, vision embarquée par deep learning et supervision logicielle temps réel. En un an, nous avons conçu et réalisé un nombre conséquent de modules — mécaniques, électroniques et logiciels — dont plusieurs sont démontrables et fonctionnels. Pour autant, l’intégration de l’ensemble de ces briques n’a pas pu être finalisée : R2B2 n’est pas en état de se déplacer de façon autonome et d’opérer seul sur un terrain de tennis.

Ce projet nous a permis de confronter les modèles théoriques à la réalité du prototypage : signaux inexploitables, débogage non concluant, mécaniques à repenser, incident sur pack batterie. Nous retenons ainsi de cette année qu’un projet d’ingénierie se construit autant sur ses défaillances que sur ses succès.

Les évolutions possibles de R2B2 sont nombreuses et constituent un périmètre de travail réaliste pour une promotion future. La finalisation de la boucle PI fermée, l’algorithme de navigation, l’intégration des capteurs ultrasons dans la logique de décision et le lien Bluetooth représentent à eux seuls une année de développement à part entière. À plus long terme, une infrastructure UWB sur les poteaux du filet et un correcteur LQR sur FPGA transformeraient R2B2 en une plateforme robotique aboutie, digne d’un usage en conditions réelles.

Nous espérons que ce travail servira de base solide à une équipe future qui pourra s’appuyer sur l’architecture existante pour franchir les étapes restantes. R2B2 n’est pas un projet terminé — c’est un projet qui mérite de l’être.

# 13. Bibliographie

[1] Wall Street Journal, The Numbers Behind the Wimbledon Serve, 2012. adresse : https://www.wsj.com/articles/SB10001424052702304724404577492903106636484.
[2] Fédération Française de Tennis, Prévention des blessures au tennis, 2023. adresse : https://www.fft.fr/pratique/sante-et-bien-etre.
[3] Tennibot Inc., Tennibot – Autonomous Tennis Ball Collector, 2024. adresse : https: //www.tennibot.com/.
[4] Slinger Bag Inc., Slinger Bag – Portable Tennis Ball Launcher, 2024. adresse : https: //www.slingerbag.com/.
[5] Intel / Terasic, DE10-Lite User Manual, 2023. adresse : https://www.terasic.com.tw/cgi-bin/page/archive.pl?Language=English&No=1021. (https://www.terasic.com.tw/cgi-bin/page/archive.pl?Language=English&No=1021)
[6] Seeed Studio, XIAO ESP32-C3 Wiki, 2023. adresse : https://wiki.seeedstudio.com/XIAO_ESP32C3_Getting_Started/. (https://wiki.seeedstudio.com/XIAO_ESP32C3_Getting_Started/)
[7] Seeed Studio, XIAO ESP32-S3 Sense Wiki, 2023. adresse : https://wiki.seeedstudio.com/xiao_esp32s3_getting_started/. (https://wiki.seeedstudio.com/xiao_esp32s3_getting_started/)
[8] Elecfreaks, HC-SR04 Ultrasonic Sensor Datasheet, 2022. adresse : https : / / cdn . sparkfun.com/datasheets/Sensors/Proximity/HCSR04.pdf. (https://cdn.sparkfun.com/datasheets/Sensors/Proximity/HCSR04.pdf)
[9] Honeywell, SS49E Linear Hall-Effect Sensor – Datasheet, 2022. adresse : https : / / sensing.honeywell.com/SS49E.
[10] Allegro MicroSystems, A3141, A3142, A3143, A3144 Hall-Effect Switches – Datasheet, 2020. adresse : https://www.elecrow.com/download/A3141-2-3-4-Datasheet. pdf. (https://www.elecrow.com/download/A3141-2-3-4-Datasheet.pdf)
[11] JGB Motors, JGB37-520 DC Geared Motor – Datasheet, Moteur 24 V 960 RPM, couple 3 kg·cm, encodeur effet Hall intégré, 2023. adresse : https://www.aliexpress.com.
[12] Mouser Electronics, 28BYJ-48 Stepper Motor – Datasheet, 2020. adresse : https : //www.mouser.com/datasheet/2/758/stepd-01-data-sheet-1143075.pdf.
[13] TowerPro, MG996R Metal Gear Servo – Datasheet, Couple max. 11 kg·cm, tension 4,8– 7,2 V, 2019. adresse : http://archive.communica.co.za/Content/Catalog/Documents/D0263792703.pdf. (http://archive.communica.co.za/Content/Catalog/Documents/D0263792703.pdf)
[14] TowerPro, SG90 Micro Servo – Datasheet, Micro servo 9 g, couple 1,8 kg·cm, 2020. adresse : http : / / www . ee . ic . ac . uk / pcheung / teaching / DE1 _ EE / stores / sg90 _ datasheet.pdf. (http://www.ee.ic.ac.uk/pcheung/teaching/DE1_EE/stores/sg90_datasheet.pdf)
[15] Infineon Technologies, BTS7960B High Current PN Half Bridge – Datasheet, Pont en H 43 A, 5,5–27 V, 2020. adresse : https://dfimg.dfrobot.com/enshop/image/data/DRI0018/BTS7960.pdf. (https://dfimg.dfrobot.com/enshop/image/data/DRI0018/BTS7960.pdf)

[16] XLSEMI, XL4015 5A 180 kHz 36 V Buck DC-DC Converter – Datasheet, Abaisseur de tension réglable 1,25–32 V, 5 A, 2020. adresse : https : / / fr . scribd . com / document / 331748365/XL4015-datasheet-pdf. (https://fr.scribd.com/document/331748365/XL4015-datasheet-pdf)
[17] Samsung SDI, INR18650-25R 2500 mAh High Drain Cell – Datasheet, Capacité 2500 mAh, décharge max. 20 A en continu, 2014. adresse : https://www.batteryspace.com/prodspecs/6408.pdf. (https://www.batteryspace.com/prod-specs/6408.pdf)
[18] MISUMI, GT2 Timing Belt – Technical Specification, Courroie pas 2 mm, largeur 6 mm, 2023. adresse : https://us.misumi-ec.com/vona2/detail/110302652060/.
[19] Edge Impulse Inc., FOMO – Faster Objects, More Objects, Architecture de détection d’objets temps réel pour microcontrôleurs, 2022. adresse : https://docs.edgeimpulse.com/studio/projects/learning-blocks/blocks/object-detection/fomo. (https://docs.edgeimpulse.com/studio/projects/learning-blocks/blocks/object-detection/fomo)
[20] J. Jongboom et al., « FOMO : Real-Time Object Detection on Microcontrollers, » in Proceedings of the tinyML Research Symposium, 2022. adresse : https://www.edge-aivision.com/wp-content/uploads/2022/05/E3W04_Jongboom_Edge_Impulse_2022.pdf. (https://www.edge-ai-vision.com/wp-content/uploads/2022/05/E3W04_Jongboom_Edge_Impulse_2022.pdf)
[21] Seeed Studio, SenseCraft AI – Model Assistant for Edge Devices, 2024. adresse : https: //sensecraft.seeed.cc/ai/.
[22] Texas Instruments, Understanding UART – Application Report SLAA749A, 2019. adresse : https://www.ti.com/lit/an/slaa749a/slaa749a.pdf.
[23] IEEE, IEEE Standard VHDL Language Reference Manual – IEEE Std 1076-2008, 2009. adresse : https://ieeexplore.ieee.org/document/4772740.

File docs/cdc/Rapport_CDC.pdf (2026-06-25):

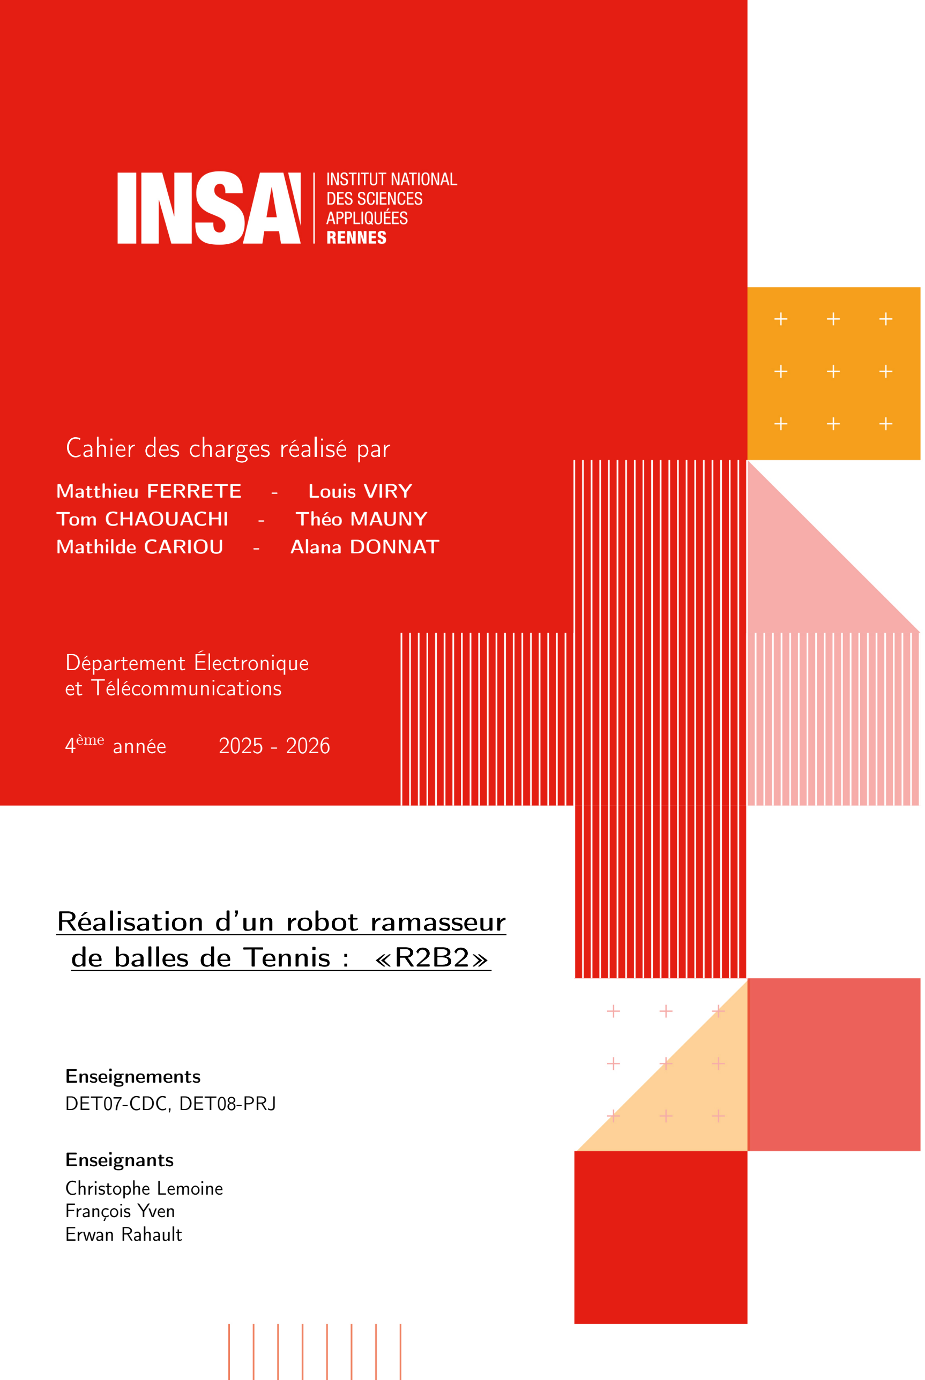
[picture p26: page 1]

## Cahier des charges réalisé par

Matthieu FERRETE | - | Louis VIRY
Tom CHAOUACHI | - | Théo MAUNY
Mathilde CARIOU | - | Alana DONNAT

## Département Électronique et Télécommunications

4

## ème année 2025 - 2026

## Réalisation d’un robot ramasseur de balles de Tennis : «R2B2»

Enseignements
DET07-CDC, DET08-PRJ

Enseignants
Christophe Lemoine
François Yven
Erwan Rahault

# Remerciements

Nous tenons à remercier les enseignants qui encadrent ce projet pour leur conseils avisés et leur accompagnement au long de la réalisation de ce cahier des charges.

Nous remercions particulièrement Gilles Picoult, pour son aide précieuse dans le choix des composants et des fournisseurs.

# Table des matières

1 Introduction | 3
2 Présentation du projet | 3
3 Description technique du projet | 8
4 Gestion financière du projet | 23
5 Organisation du projet | 25
6 Bibliographie | 28

# 1. Introduction

L’évolution technologique dans le domaine du sport a considérablement transformé la pratique de haut niveau comme celle des amateurs. Si les équipements tels que les raquettes, les chaussures ou les surfaces de jeu ont bénéficié d’innovations majeures en science des matériaux, la logistique même du jeu de tennis est restée relativement classique. Encore aujourd’hui, la gestion des balles sur le terrain repose presque exclusivement sur l’intervention humaine même dans le tennis de haut niveau, en compétition, etc...

Le tennis est un sport fragmenté par nature. La dynamique du jeu est constamment interrompue par la nécessité de récupérer les balles qui n’ont pas franchi le filet ou qui sont sorties des limites du court. Dans le contexte des grands tournois, cette tâche est déléguée à des ramasseurs de balles humains, formés et rapides. Cependant, pour l’immense majorité des pratiquants, soit plus de 99% des joueurs dans le monde, cette corvée incombe aux joueurs eux-mêmes.

Notre projet s’inscrit dans une démarche de robotique de service appliquée au sport. Il vise à concevoir une solution mécatronique autonome capable de fluidifier le jeu. La singularité de notre approche réside dans le mode opératoire du robot. Contrairement aux solutions existantes qui nettoient le terrain une fois la session terminée, notre système a pour ambition d’opérer en continu durant le match. Il s’agit de développer un robot capable de cohabiter avec les joueurs, d’identifier les balles mortes et de les collecter en temps réel sans jamais interférer avec la trajectoire de la balle en jeu ni gêner les déplacements des sportifs. Ce défi impose des contraintes techniques fortes en matière de détection, de navigation, de sécurité et de réactivité.

# 2. Présentation du projet

### 2.1 Analyse du besoin

Pour justifier la pertinence de ce projet, nous avons analysé les impacts du ramassage manuel sous quatre angles fondamentaux : l’efficacité temporelle, la sécurité physique, l’inclusion sociale et la rentabilité économique.

### 2.1.1 Optimisation du temps de jeu

Le tennis souffre d’un ratio temps de jeu sur temps de présence particulièrement faible. Une étude statistique relayée par le Wall Street Journal a mis en lumière que sur une rencontre professionnelle d’une durée de trois heures, le temps de jeu effectif, c’est-à-dire le moment où la balle est réellement en échange, ne représente que 17,5% du temps total. Cela correspond à peine à 21 minutes d’action réelle.
Ce constat est encore plus sévère lors des entraînements amateurs. Lorsqu’un joueur effectue une série de services ou un exercice au panier, le ramassage manuel des 50 à 100 balles dispersées peut prendre entre 5 et 8 minutes. Sur une séance d’une heure, la répétition de cette tâche empiète sur le temps de pratique de 20% à 30%. L’automatisation de ce processus permettrait de récupérer ce temps perdu pour le consacrer à l’apprentissage technique et au plaisir du jeu.

### 2.1.2 Sécurité et prévention des blessures

La présence de balles immobiles sur la surface de jeu constitue un risque avéré pour l’intégrité physique des joueurs. Les déplacements au tennis sont caractérisés par des courses latérales, des reprises d’appuis violentes et des reculs précipités pour se replacer en fond de court. Par conséquent, une partie significative des accidents surviennent non pas à cause de l’effort mais par un appui instable sur une balle qui traîne.
Si un joueur pose le pied sur une balle qui traîne lors d’un de ces mouvements, la cheville subit une torsion immédiate. Selon les données de la Fédération Française de Tennis et des études en traumatologie sportive, l’entorse de la cheville représente environ 25% des blessures au tennis. En assurant un nettoyage continu de la zone d’évolution, notre robot agit comme un dispositif de sécurité active permettant de réduire fortement la probabilité de chute et de lésion ligamentaire.

### 2.1.3 Accessibilité et Handisport

L’aspect inclusif est un pilier central de notre réflexion. Pour les joueurs de tennis en fauteuil roulant, la contrainte du ramassage est décuplée. Si l’handicap est moteur, l’action de ramasser une balle au sol est complexe. La biomécanique du ramassage en position assise impose des manœuvres supplémentaires avec le fauteuil et une flexion du tronc qui peut s’avérer éprouvante physiquement voire impossible selon la pathologie du joueur.
Cette difficulté constitue parfois un frein à la pratique ou une source de découragement pour les débutants. En déléguant cette tâche à un système autonome, nous redonnons de l’autonomie aux joueurs en situation de handicap, leur permettant de se focaliser uniquement sur leur performance sportive et leur plaisir de jeu sans dépendre d’une tierce personne.

### 2.2 Solution proposée

Pour répondre aux besoins identifiés ci-dessus, notre projet se fixe plusieurs objectifs techniques précis qui guideront la conception électronique et mécanique.

### 2.2.1 Sécurité et détection

C’est la priorité absolue du fonctionnement en mode continu. Le robot doit être capable de cartographier son environnement immédiat pour distinguer une balle inerte d’un joueur en mouvement. La principale contrainte est que le système puisse détecter la présence d’un joueur ou d’un obstacle non identifié dans un rayon de sécurité défini. Notre objectif est de garantir un arrêt total ou une manœuvre d’évitement si un humain pénètre dans une zone de 1 mètre autour du robot. La chaîne de traitement allant de la détection par les capteurs à l’arrêt des moteurs doit être extrêmement courte. Nous visons un temps de latence inférieur à 100 millisecondes pour éviter tout risque de collision accidentelle si un joueur recule brusquement.

### 2.2.2 Compacité et discrétion

Le robot ne doit pas devenir une nuisance visuelle. Il doit se faire oublier, ne pas se faire remarquer par les joueurs pour éviter de les perturber ou interrompre l’échange. La hauteur totale du robot ne doit pas excéder 25 centimètres afin de pouvoir circuler librement sous le filet et ne pas entrer dans le champ de vision direct des joueurs lors des phases de frappe. Pour être agile, le robot doit pouvoir pivoter sur lui-même sans avancer. Nous visons une architecture à entraînement différentiel capable de demi-tours instantanés pour s’extraire des coins du court ou fuir la trajectoire d’un joueur. De plus, la motorisation doit être silencieuse pour ne pas perturber la concentration (niveau sonore inférieur à 50 décibels).

### 2.2.3 Performances et autonomie

Pour être efficace entre deux points, le robot doit être rapide. Une vitesse de déplacement cible supérieure à 5 mètres par seconde est nécessaire pour intervenir rapidement durant les temps morts. La batterie embarquée doit garantir une autonomie couvrant la durée moyenne d’un match complet, soit environ 2 heures d’utilisation donc une capacité de 5000 mAh.

### 2.2.4 Ramassage

Le système de ramassage doit être universel et robuste. Le taux de réussite de la collecte au premier passage doit être supérieur à 90%, même si la balle est encore légèrement en mouvement. Le compromis entre compacité et utilité nous mène à viser un réservoir capable de contenir entre 10 et 15 balles. Cela correspond à la quantité de balles généralement utilisée lors d’un cycle de jeu avant un ramassage complet.

### 2.3 État de l’art

Nous nous sommes intéressés aux différentes technologies existantes, manuelles ou automatisées, afin d’étudier la concurrence et d’identifier les nouveautés à apporter et les bonnes idées garder pour notre projet

### 2.3.1 Les solutions manuelles

- Le tube de ramassage

C’est un tube en plastique ou en métal avec un clapet anti-retour. Pour faire entrer la balle dans le tube, on appuie dessus.

Avantage : Il est très peu coûteux (moins de 20 euros) et il est facilement transportable et évite de se baisser complètement.
Inconvénient : Il exige un effort physique répétitif pour l’utilisateur, et implique de ramasser chaque balle une par une.


Figure 1 – Tube de ramassage

- Le rouleau de ramassage

Il s’agit d’un rouleau que l’on doit pousser sur le court. Il est conçu avec des barreaux souples qui s’écartent lorsque l’on roule sur une balle, permettant ainsi de la récupérer et de la stocker dans le panier.

Avantage : Il permet de ramasser les balles rapidement et a une grande capacité de stockage (jusqu’à 60 balles).
Inconvénient : Il est encombrant et nécessite toujours une action humaine.


Figure 2 – Rouleau de ramassage

### 2.3.2 Les solutions automatisées

- Le Tennibot

Il s’agit d’un robot ramasseur de balles autonome dont le fonctionnement est similaire à celui d’un aspirateur robot, mais adapté au tennis. Son système de navigation est basé sur l’intelligence artificielle. Le robot se déplace de manière autonome pour les collecter.

Avantage : Il agit en autonomie totale (le joueur joue pendant que le robot ramasse les balles).
Inconvénient : Le prix est excessif pour un amateur ou joueur loisir (˜2245$) et sa vitesse de ramassage est lente. Sa capacité de stockage est limitée.


Figure 3 – Tennibot

- Le Slinger Bag

Il s’agit d’un système robotisé permettant la distribution de balles selon plusieurs paramètres (fréquence, vitesse, effets).

Avantage : Il permet d’effectuer des sessions d’entraînement personnalisées sans partenaire au moment souhaité.
Inconvénient :Il est conçu uniquement pour la distribution mais n’intègre aucune fonction de collecte. L’utilisateur doit forcément interrompre l’entraînement pour ramasser manuellement les balles et recharger la machine.


Figure 4 – Slinger Bag

# 3. Description technique du projet

### 3.1 Module de déplacement

Ce module est essentiel car c’est celui qui gère la première phase de la recherche de la balle tout en assurant la sécurité des joueurs et du robot lui-même.

Pour le réaliser, nous avons pensé à plusieurs options, mais il faut d’abord diviser le problème en trois sous-parties :

- Comment assurer la rapidité et la fluidité du robot tout en maintenant sa stabilité ?
- La stratégie de déplacement : Comment va-t-on faire se déplacer le robot sur le terrain ?
- Quels capteurs allons-nous utiliser ? Et pourquoi ?

### 3.1.1 Stabilité du robot

L’objectif de notre robot est d’être en marche pendant le match, il doit donc ramasser les balles le plus rapidement possible sans nuire aux joueurs. C’est pourquoi il doit être rapide et compact.

Dans un premier temps nous avons donc imaginé un robot sur deux roues, tenant en équilibre grâce à un système d’auto-balancement. Cette solution permettait une certaine vivacité du robot mais créait en contrepartie une instabilité de celui-ci. Lorsqu’un robot est en auto-balancement, il corrige constamment son inclinaison pour garder l’équilibre et ne pas se renverser par terre. Cela compliquait donc énormément les mouvements du robot notamment pour la détection et le ramassage de la balle.

Nous nous sommes donc orientés sur une solution à trois roues avec deux roues motrices à l’avant et une roue folle à l’arrière du robot. Cela nous permet de garder la vivacité du modèle précédent tout en assurant sa stabilité. De plus, cela nous dégage plus de temps pour nous concentrer sur les autres parties du projet qui sont déjà tout aussi denses.

### 3.1.2 Stratégie de déplacement du robot

- Déplacement aléatoire

Le robot se déplace de manière aléatoire sur le terrain jusqu’à ce qu’il trouve une balle. Deux cas possibles : si on a de la chance, on peut trouver rapidement la balle, mais au contraire, si le robot ne passe pas à côté de la balle, le temps d’attente avant la détection peut être relativement long. Puisque nous ne voulons pas que l’efficacité de notre robot soit impactée par le facteur chance, nous écartons naturellement cette solution.

- Le déplacement par bande

Le robot parcourt tout le terrain en le traversant dans sa largeur et recommence ainsi de suite en se décalant jusqu’à l’autre bout du terrain. Le point positif est que le robot parcourt la totalité du terrain et est donc certain de détecter une balle à un moment, cependant il n’est pas très efficace car il passe du temps là où il n’y a que peu de chance de trouver une balle. En effet, lors d’un match de tennis, il y a peu de chance que la balle s’arrête en plein milieu du terrain, elle se trouvera plutôt au fond du court ou au filet. De plus, étant donné que l’objectif du robot, à terme, est de fonctionner durant le match, il n’est pas concevable qu’il passe à l’intérieur du terrain pendant le jeu. Cette solution n’a donc pas été retenue.

- Le déplacement en "O"

Le robot fait le tour du terrain à l’extérieur des lignes pour permettre le jeu en simultané. Il récupère les balles qui se trouvent dans le fond du court (voir Figure 5). Cette solution est plus efficace car elle se concentre uniquement sur les zones où la balle a de réelles chances de se trouver, cependant elle ne couvre pas l’espace devant le filet et peut donc laisser des balles sur le terrain.


Figure 5 – Déplacement en "O"

- Le déplacement en "8"

C’est l’option la plus efficace, elle reprend la stratégie précédente en prenant en compte la zone devant le filet. Le robot parcourt toutes les zones du terrain où les balles sont susceptibles de se trouver. Le parcours retenu pour maximiser la probabilité de croiser une balle est en forme de “8” (voir figure 6). En supposant que la balle ait fini sa course soit en fond de court, soit dans le filet, le robot devrait alors trouver toutes les balles lors de son tour de terrain.


Figure 6 – Déplacement en "8"

Nous mettrons d’abord en place la stratégie de déplacement en “0” puis, une fois celle-ci fonctionnelle, nous essayerons la stratégie de déplacement en “8” pour rendre notre robot plus complet.

### 3.1.3 Les capteurs

Maintenant que nous avons sélectionné notre stratégie de déplacement, nous devons voir quels capteurs nous allons utiliser pour pouvoir mettre en œuvre cette stratégie :

- Se repérer

Pour assurer ce déplacement, il faut que le robot puisse se repérer sur le terrain et éviter les obstacles. De plus, pour pouvoir appliquer les stratégies de déplacement retenues, le robot doit pouvoir détecter les grillages du terrain pour les longer et faire le tour du terrain comme expliqué précédemment. Pour réaliser toutes ces fonctionnalités, nous avons choisi d’utiliser des capteurs à ultrasons. En plus de nous fournir les informations sur les obstacles environnants, nécessaires au déplacement du robot, ces capteurs sont insensibles aux conditions extérieures comme la luminosité ou le bruit, ce qui est important dans notre cas. Par ailleurs, avec une détection jusqu’à 4 mètres et 15 rafraîchissements par seconde, ce capteur nous a paru intéressant dès le départ. Afin de garantir une détection optimale et complète, nous avons choisi de placer 8 capteurs sur le pourtour du robot, un sur chaque face et un dans chaque angle (voir figure 7). Cette disposition nous permet d’avoir des informations sur des obstacles venant de n’importe quel côté, ce qui est indispensable pour les déplacements du robot, notamment lors des manœuvres de récupération de la balle.


Figure 7 – Portée des capteurs à ultrasons

- Implémenter

Maintenant que nous savons où doit aller notre robot et qu’il peut détecter les obstacles, nous devons coder l’algorithme de déplacement, c’est ce dernier qui va contrôler les roues en fonction des informations transmises par les capteurs. En théorie, la logique de celui-ci est plutôt simple : le robot longe les grillages sur les côtés extérieurs du terrain en gardant une distance la plus constante possible avec ce dernier.

Lors de cette phase, 2 cas peuvent arriver :

— Le robot détecte le grillage de face : le robot arrive au bout du terrain. Dans ce cas, le robot décélère pour aborder le virage de manière stable, une fois au bout du terrain il tourne, détecte le grillage sur son côté et poursuit son chemin sur ce nouveau côté.

— Le robot détecte le filet (pour le déplacement en “8” uniquement) : le robot est au milieu d’un des deux côtés. Dans ce cas, le robot doit traverser le terrain juste devant le filet. Pour ce faire, le robot décélère et tourne de 90°. Ici, il est probable que le filet ne soit pas détecté par les capteurs à ultrason (dû au maillage et au matériau), on doit donc, pour être certain que le robot ne heurte pas le filet, prévoir une marge de quelques degrés ou alors que le robot traverse le terrain moins proche du filet pour qu’en cas de décalage, il n’y ait pas d’accident. Une fois de l’autre côté du terrain et lorsque le robot détecte le grillage d’en face, il décélère puis tourne à nouveau de 90° à nouveau avant de reprendre son parcours.

Les stratégies de déplacement du robot et de contrôle des moteurs seront implémentées dans une carte par un programme en C++ via Arduino IDE.

En se déplaçant ainsi, le robot devrait détecter une balle. C’est à ce moment que la partie “détection” prend le relais.

- Se déplacer

Après calculs, il a été démontré que les deux moteurs principaux gérant le déplacement nécessitaient un couple supérieur à 1N.m et une vitesse de 600rpm minimum avec des roues de 105mm pour tracter le robot et le faire atteindre les 3m/s en moins de 4s. Le moteur JGB37-520 (voir Figure 8) a alors été choisi, statisfaisant l’ensemble des critères.


Figure 8 – Moteur JGB37-520

### 3.2 Module de détection

### 3.2.1 Solutions envisagées

Avant d’arrêter notre choix sur l’architecture finale, nous avons étudié et comparé plusieurs approches techniques pour répondre aux besoins de détection et de déclenchement.

Le premier choix a été le déclenchement par contact mécanique avec un micro-switch. Le principe se basait sur l’installation d’un bouton poussoir ou d’un capteur de fin de course à l’avant du robot, au niveau du sol, qui aurait permis d’enclencher le système de ramassage uniquement lorsque la balle percute physiquement ce capteur. Bien que cette solution semblait fiable et peu coûteuse, elle restait tout de même très peu fluide. Elle obligeait le robot à entrer en collision avec la balle pour réagir, imposant un ralentissement progressif avant le contact et augmentait la quantité d’informations pour la carte.

La deuxième option était celle par mesure de la distance par écho sonore, qui a été écartée et déplacée dans une autre partie de notre robot. En effet, elle était bien trop complexe et semblait inutile au moment pour le ramassage.

Finalement, l’option retenue a été l’estimation par vision, mais pas celle prévue initialement avec l’utilisation d’une caméra statique. Cette dernière créait un angle mort important devant les roues du robot, risquant de faire perdre de vue la cible dans la phase finale de ramassage. Dans ce dernier choix, plusieurs caméras ont été comparées. Dans un premier temps, le Raspberry Pi avec sa caméra Pi, puisqu’elle nous offrait la puissance de calcul nécessaire. Elle a été écartée car son coût représentait à lui seul la moitié du budget total du robot, et sa consommation électrique était trop importante. La deuxième caméra que nous avons comparée a été la ESP32-CAM en raison de son prix, mais elle a été écartée à cause de son taux de FPS trop faible pour voir à 5 mètres.

### 3.2.2 Solutions retenues

- Servomoteur SG90

Pour pallier l’absence de vision périphérique et l’angle mort au sol, nous avons opté pour une tête mobile dirigée par un servomoteur. Pour ce faire, notre choix s’est porté sur le servomoteur SG90, ne pesant que 9 grammes et très peu coûteux. Pour la connexion, il n’y a besoin que de 3 fils (5V, GND, signal PWM), le fil pour le signal étant connecté à une broche (pin) de la XIAO ESP32-S3 (caméra).


Figure 9 – Servomoteur SG90

Cette méthode comporte plusieurs parties. Dans un premier temps, la phase de recherche (le scan) : le servomoteur met la caméra à l’horizontale et regarde à une distance de 5 à 6 mètres. Le premier problème survient lorsqu’on a un cas de « balles multiples » ; en effet, nous avons dû implémenter une logique de sélection stricte. Tout d’abord, nous appliquons un critère de priorité : le robot scanne l’image et la première règle est de repérer le « blob » de pixels le plus gros, qui sera donc souvent le plus proche. Si deux blobs ont la même taille, la deuxième règle consiste à prendre celui le plus proche du centre de l’image. Une fois le verrouillage effectué, le robot ignore toutes les autres balles, même si une autre devient plus grosse ou passe à côté. La cible ne change que si elle est ramassée ou si elle disparaît. L’objectif est d’avoir un suivi dynamique qui permet de supprimer totalement l’angle mort, la balle restant toujours au centre de l’image.

- Le XIAO ESP32-S3 Sense

L’objectif reste d’isoler la balle dans un environnement complexe en raison du terrain, des lignes et du soleil. Pour cela, nous allons utiliser le module XIAO ESP32-S3 Sense, suffisamment puissant avec une résolution SVGA (800x600) pour garantir une détection jusqu’à 6 mètres avec un traitement en temps réel d’environ 20 FPS. Pour le traitement, nous allons dans un premier temps effectuer une conversion colorimétrique en passant du RGB au HSV (pour travailler en Teinte/Saturation/Valeur) afin de s’affranchir des variations de luminosité dues à l’ombre ou au soleil. Nous allons ensuite définir un seuil « Jaune Tennis » pour pouvoir détecter les balles et les identifier en remarquant les amas de pixels jaunes connectés.

Ce module va aussi nous permettre d’obtenir les coordonnées du barycentre de la balle, qui vont chacune piloter un actionneur différent. La coordonnée en X va permettre de guider les roues : si le X de la balle n’est pas au centre, le robot va pivoter sur la droite ou sur la gauche en conséquence. L’axe X est donc envoyé au contrôleur des roues pour aligner le robot face à la balle. Quant à la coordonnée Y, elle va nous permettre de garder la balle au centre de l’image en indiquant au servomoteur s’il doit baisser ou remonter la tête en fonction de l’angle nécessaire, avec pour but de ne jamais perdre la balle de vue. L’axe Y est donc utilisé par l’algorithme de tracking pour incliner la caméra et maintenir la cible au centre de l’écran.


Figure 10 – Robot R2B2, caméra vers le sol

### 3.2.3 Gestion de la distance

Plutôt que d’utiliser un capteur laser coûteux, nous utilisons la géométrie du système. Puisque le servomoteur incline la caméra pour garder la balle au centre, l’angle du moteur est directement lié à la distance. On utilise donc la formule :

d =

hservo

tan(θservo)

Nous utilisons donc une triangulation, méthode beaucoup plus précise que l’estimation par la taille des pixels, et qui n’a qu’un coût logiciel. La distance va aussi permettre de définir des seuils de puissance pour les moteurs des roues. En effet, lorsque nous calculons une distance supérieure à 2 mètres par exemple, les moteurs seront à 100%. Lorsque la distance sera inférieure, nous réduirons la puissance des moteurs.


Figure 11 – Asservissement du servomoteur

### 3.3 Module de ramassage
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

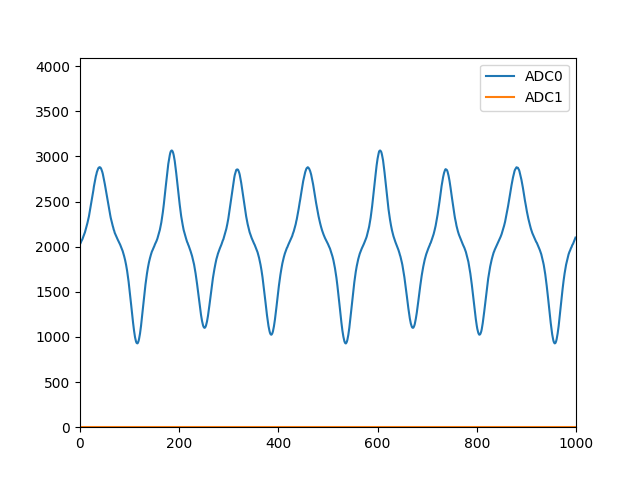
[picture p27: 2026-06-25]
software/monitor/img/adc_mesure_5V.png

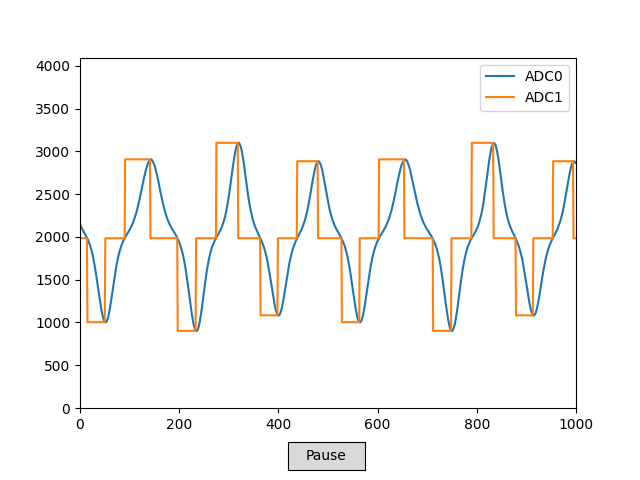
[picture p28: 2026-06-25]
software/monitor/img/adc_mesure_paliers.png

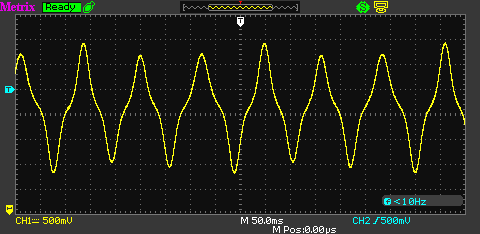
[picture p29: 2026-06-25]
software/monitor/img/oscilo_mesure_5V.BMP

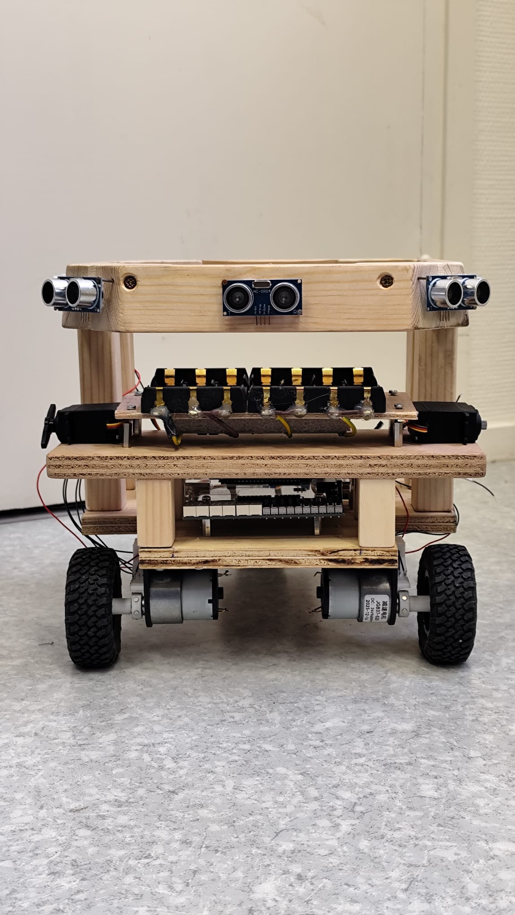
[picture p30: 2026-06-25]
structure/robot/robot_0.jpeg

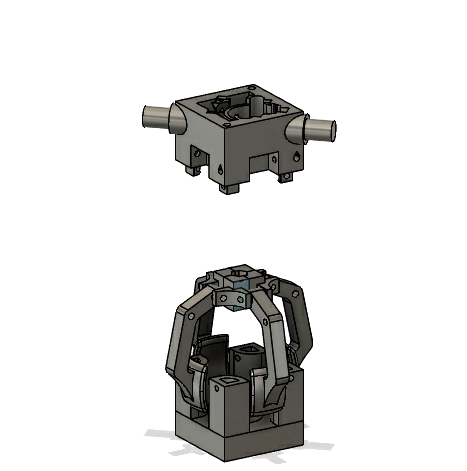
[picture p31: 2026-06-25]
structure/pince/Capture d’écran du 2026-05-18 06-07-25.png

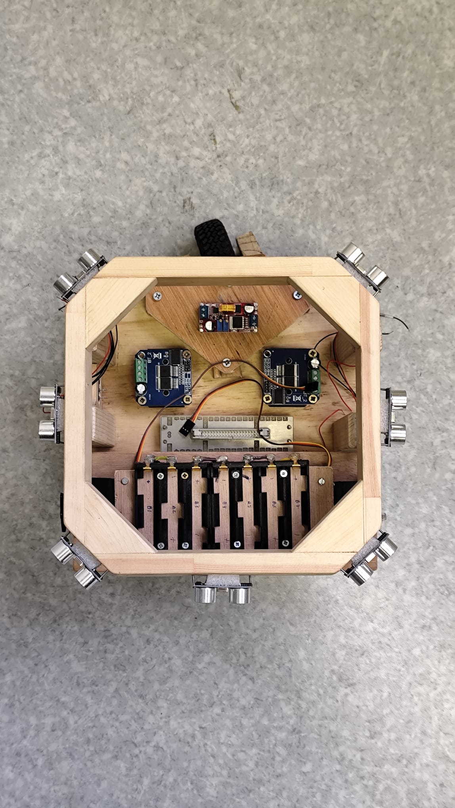
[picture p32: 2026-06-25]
structure/robot/robot_1.jpeg

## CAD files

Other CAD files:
hardware/cao/pince.f3z
hardware/cao/robot.f3z

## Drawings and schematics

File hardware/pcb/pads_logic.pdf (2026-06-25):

D

6 | 5 | 4 | 3 | 2 | 1

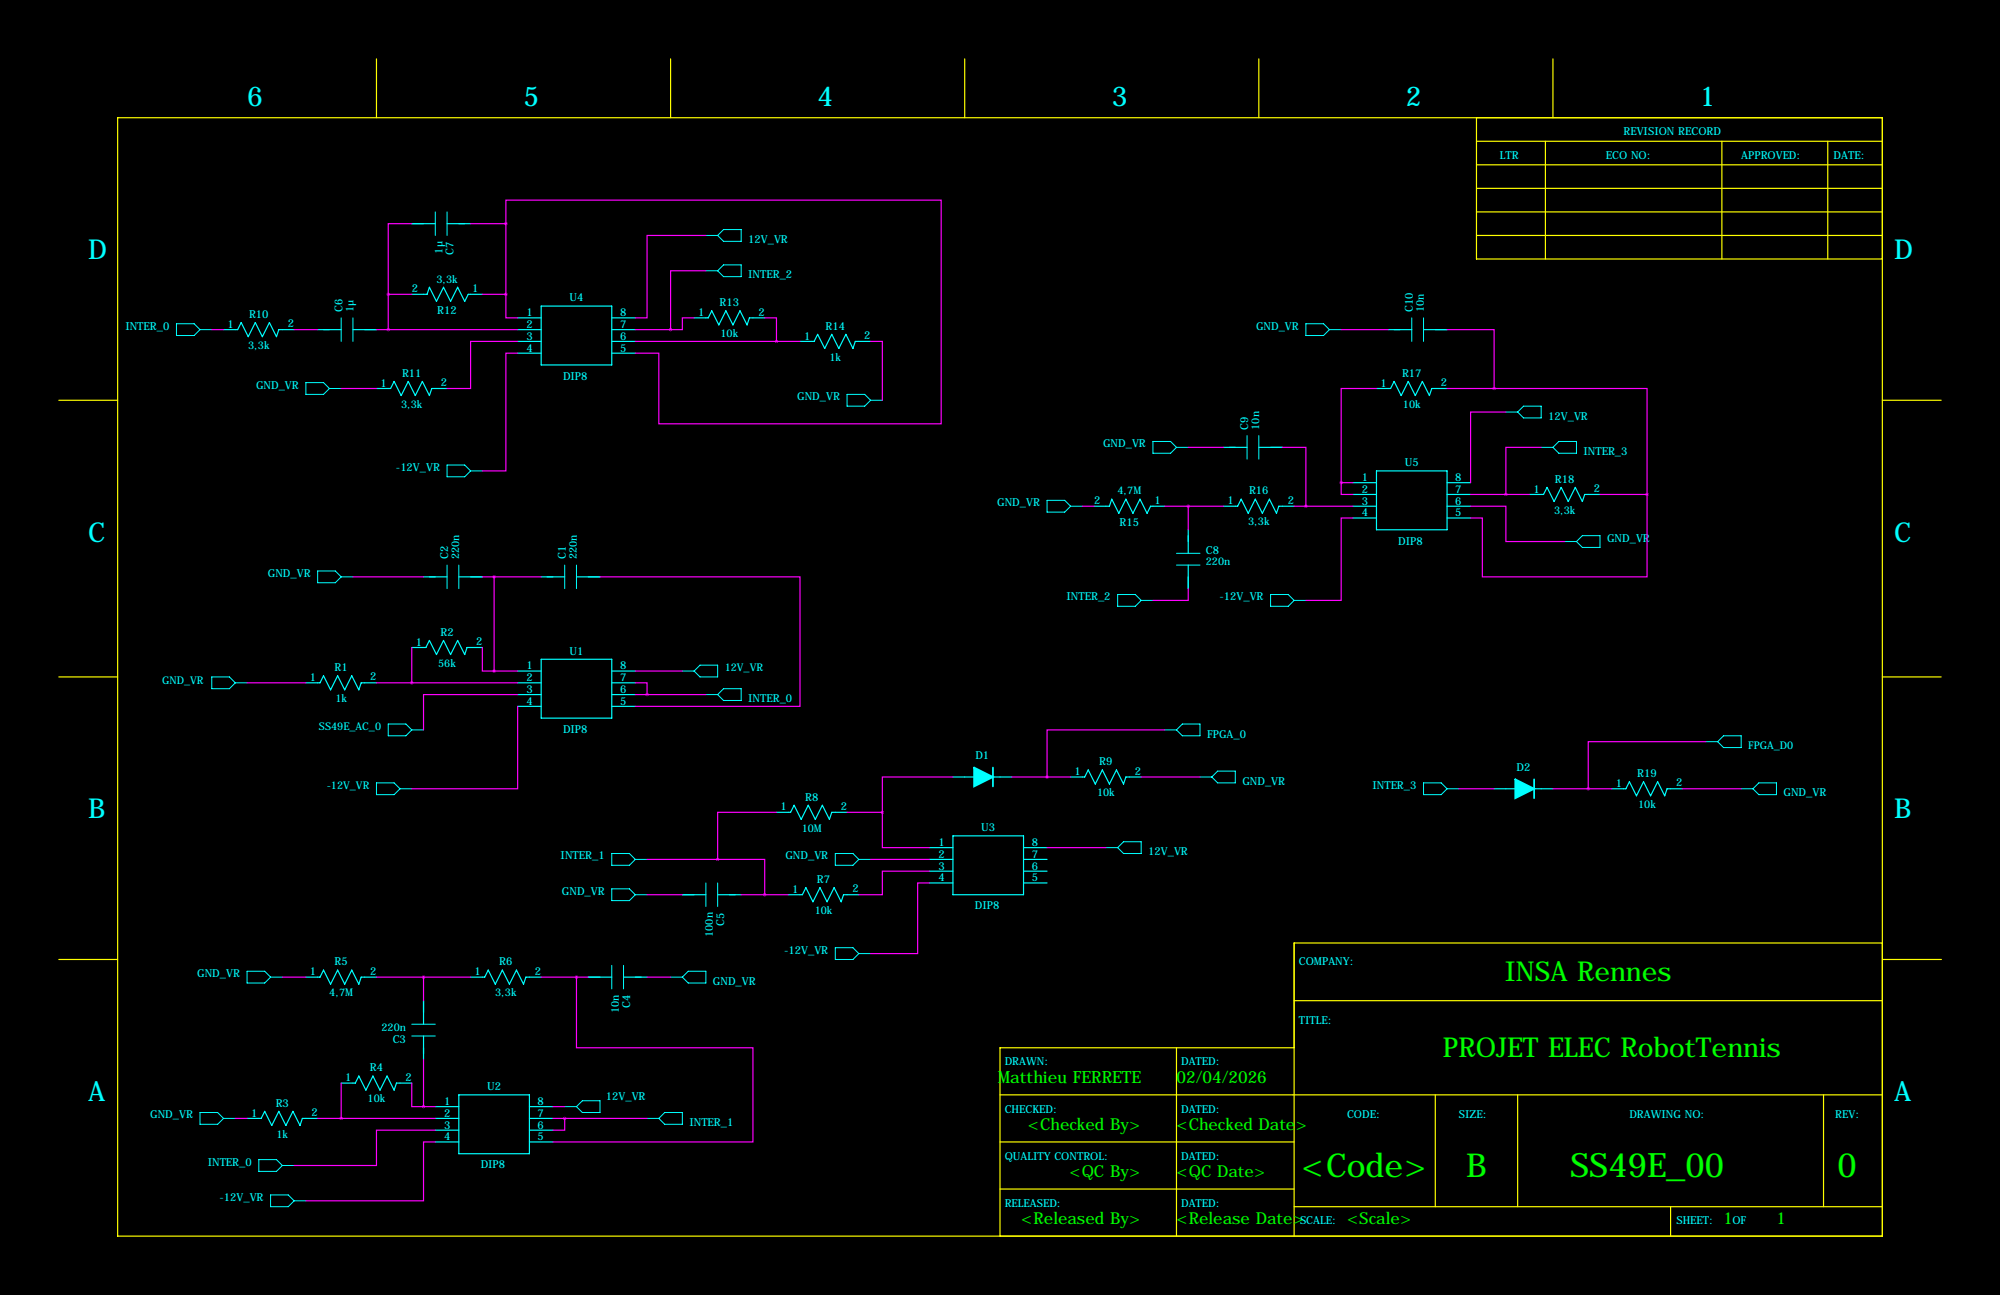
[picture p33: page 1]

REVISION RECORD

LTR | ECO NO: | APPROVED: | DATE:

DRAWN: Matthieu FERRETE | DATED: 02/04/2026
CHECKED: <Checked By> | DATED: <Checked Date> | CODE: <Code> | SIZE: B | DRAWING NO: SS49E_00 | REV: 0

QUALITY CONTROL: <QC By> | DATED: <QC Date>

RELEASED: <Released By> | DATED:

<Scale> SCALE: | 1 1 SHEET: OF

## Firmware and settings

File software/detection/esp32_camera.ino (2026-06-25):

#include <Suprematy-project-1_inferencing.h>
#include "edge-impulse-sdk/dsp/image/image.hpp"
#include "esp_camera.h"

// Pins XIAO ESP32S3
#define PWDN_GPIO_NUM     -1
#define RESET_GPIO_NUM    -1
#define XCLK_GPIO_NUM     10
#define SIOD_GPIO_NUM     40
#define SIOC_GPIO_NUM     39
#define Y9_GPIO_NUM       48
#define Y8_GPIO_NUM       11
#define Y7_GPIO_NUM       12
#define Y6_GPIO_NUM       14
#define Y5_GPIO_NUM       16
#define Y4_GPIO_NUM       18
#define Y3_GPIO_NUM       17
#define Y2_GPIO_NUM       15
#define VSYNC_GPIO_NUM    38
#define HREF_GPIO_NUM     47
#define PCLK_GPIO_NUM     13

// --- LED ---
#define LED_PIN           2   // ← ajuste selon ton câblage

// --- SEUILS ---
const int   BBOX_PROCHE   = 20;  // ← ta valeur calibrée (T_FILT à 20cm)
const int   ANGLE_TOL     = 10;  // ± pixels autour du centre

#define EI_CAMERA_RAW_FRAME_BUFFER_COLS  320
#define EI_CAMERA_RAW_FRAME_BUFFER_ROWS  240
#define EI_CAMERA_FRAME_BYTE_SIZE        3

static bool is_initialised = false;
uint8_t *snapshot_buf;
float t_filtered = 0;
const float ALPHA = 0.1;

static camera_config_t camera_config = {
    .pin_pwdn  = PWDN_GPIO_NUM,
    .pin_reset = RESET_GPIO_NUM,
    .pin_xclk  = XCLK_GPIO_NUM,
    .pin_sccb_sda = SIOD_GPIO_NUM,
    .pin_sccb_scl = SIOC_GPIO_NUM,
    .pin_d7 = Y9_GPIO_NUM, .pin_d6 = Y8_GPIO_NUM,
    .pin_d5 = Y7_GPIO_NUM, .pin_d4 = Y6_GPIO_NUM,
    .pin_d3 = Y5_GPIO_NUM, .pin_d2 = Y4_GPIO_NUM,
    .pin_d1 = Y3_GPIO_NUM, .pin_d0 = Y2_GPIO_NUM,
    .pin_vsync = VSYNC_GPIO_NUM,
    .pin_href  = HREF_GPIO_NUM,
    .pin_pclk  = PCLK_GPIO_NUM,
    .xclk_freq_hz = 20000000,
    .ledc_timer   = LEDC_TIMER_0,
    .ledc_channel = LEDC_CHANNEL_0,
    .pixel_format = PIXFORMAT_JPEG,
    .frame_size   = FRAMESIZE_QVGA,
    .jpeg_quality = 12,
    .fb_count     = 1,
    .fb_location  = CAMERA_FB_IN_PSRAM,
    .grab_mode    = CAMERA_GRAB_WHEN_EMPTY,
};

bool ei_camera_init(void);
bool ei_camera_capture(uint32_t img_width, uint32_t img_height, uint8_t *out_buf);

bool ei_camera_init(void) {
    if (is_initialised) return true;
    esp_err_t err = esp_camera_init(&camera_config);
    if (err != ESP_OK) {
        Serial.printf("Camera init failed: 0x%x\n", err);
        return false;
    }
    sensor_t *s = esp_camera_sensor_get();
    s->set_vflip(s, 1);
    s->set_hmirror(s, 0);
    s->set_saturation(s, 2);
    is_initialised = true;
    return true;
}

bool ei_camera_capture(uint32_t img_width, uint32_t img_height, uint8_t *out_buf) {
    if (!is_initialised) return false;
    camera_fb_t *fb = esp_camera_fb_get();
    if (!fb) return false;
    bool converted = fmt2rgb888(fb->buf, fb->len, PIXFORMAT_JPEG, snapshot_buf);
    esp_camera_fb_return(fb);
    if (!converted) return false;
    if ((img_width != EI_CAMERA_RAW_FRAME_BUFFER_COLS)
        || (img_height != EI_CAMERA_RAW_FRAME_BUFFER_ROWS)) {
        ei::image::processing::crop_and_interpolate_rgb888(
            out_buf,
            EI_CAMERA_RAW_FRAME_BUFFER_COLS,
            EI_CAMERA_RAW_FRAME_BUFFER_ROWS,
            out_buf, img_width, img_height);
    }
    return true;
}

static int ei_camera_get_data(size_t offset, size_t length, float *out_ptr) {
    size_t pixel_ix    = offset * 3;
    size_t pixels_left = length;
    size_t out_ptr_ix  = 0;
    while (pixels_left != 0) {
        out_ptr[out_ptr_ix] = (snapshot_buf[pixel_ix + 2] << 16)
                            + (snapshot_buf[pixel_ix + 1] << 8)
                            +  snapshot_buf[pixel_ix];
        out_ptr_ix++;
        pixel_ix += 3;
        pixels_left--;
    }
    return 0;
}

void setup() {
    Serial.begin(115200);
    delay(1000);

    pinMode(LED_PIN, OUTPUT);
    digitalWrite(LED_PIN, LOW);

    if (ei_camera_init() == false) {
        Serial.println("Erreur camera !");
    } else {
        Serial.println("Camera OK - pret !");
    }
    delay(2000);
}

void loop() {
    snapshot_buf = (uint8_t*)malloc(EI_CAMERA_RAW_FRAME_BUFFER_COLS *
                                    EI_CAMERA_RAW_FRAME_BUFFER_ROWS *
                                    EI_CAMERA_FRAME_BYTE_SIZE);
    if (snapshot_buf == nullptr) {
        Serial.println("ERR: malloc");
        delay(500);
        return;
    }

    ei::signal_t signal;
    signal.total_length = EI_CLASSIFIER_INPUT_WIDTH * EI_CLASSIFIER_INPUT_HEIGHT;
    signal.get_data = &ei_camera_get_data;

    if (ei_camera_capture((size_t)EI_CLASSIFIER_INPUT_WIDTH,
                          (size_t)EI_CLASSIFIER_INPUT_HEIGHT,
                          snapshot_buf) == false) {
        free(snapshot_buf);
        delay(500);
        return;
    }

    ei_impulse_result_t result = { 0 };
    EI_IMPULSE_ERROR err = run_classifier(&signal, &result, false);
    if (err != EI_IMPULSE_OK) {
        free(snapshot_buf);
        delay(500);
        return;
    }

#if EI_CLASSIFIER_OBJECT_DETECTION == 1
    // Trouve la meilleure balle
    int best_score = -9999;
    int best_idx   = -1;

    for (uint32_t i = 0; i < result.bounding_boxes_count; i++) {
        ei_impulse_result_bounding_box_t bb = result.bounding_boxes[i];
        if (bb.value < 0.3) continue;
        int cx      = bb.x + bb.width / 2;
        int offsetX = abs(cx - (EI_CLASSIFIER_INPUT_WIDTH / 2));
        int score   = (int)bb.width - offsetX;
        if (score > best_score) {
            best_score = score;
            best_idx   = i;
        }
    }

    if (best_idx >= 0) {
        ei_impulse_result_bounding_box_t bb = result.bounding_boxes[best_idx];
        int cx      = bb.x + bb.width / 2;
        int taille  = bb.width;
        int offsetX = abs(cx - (EI_CLASSIFIER_INPUT_WIDTH / 2));

        // Filtre
        if (t_filtered == 0) t_filtered = taille;
        t_filtered = ALPHA * taille + (1.0 - ALPHA) * t_filtered;

        // Condition ramassage : balle proche ET centrée
        bool proche  = (t_filtered >= BBOX_PROCHE);
        bool centree = (offsetX <= ANGLE_TOL);

        if (proche && centree) {
            digitalWrite(LED_PIN, HIGH);  // LED allumée → position ramassage !
            Serial.println(">>> POSITION RAMASSAGE <<<");
        } else {
            digitalWrite(LED_PIN, LOW);
            if (!centree)
                Serial.printf("Recentrer : offsetX=%d\n", offsetX);
            else
                Serial.printf("Approcher : T_FILT=%.1f\n", t_filtered);
        }

        Serial.printf("Taille:%d T_FILT:%.1f OffsetX:%d Score:%.2f\n",
                      taille, t_filtered, offsetX, bb.value);
    } else {
        digitalWrite(LED_PIN, LOW);
        t_filtered = 0;
        Serial.println("Aucune balle");
    }
#endif

    free(snapshot_buf);
    delay(100);
}

#if !defined(EI_CLASSIFIER_SENSOR) || EI_CLASSIFIER_SENSOR != EI_CLASSIFIER_SENSOR_CAMERA
#error "Invalid model for current sensor"
#endif

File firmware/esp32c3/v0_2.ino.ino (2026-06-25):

// ============================================================
// Récepteur trame UART DE10-Lite → ESP32-C3
// Format : 0xAA | 0x02 | LSB | MSB | CHECKSUM(XOR)
// Sortie Serial (USB) : "0,valeur" ou "1,valeur" pour Python
// ============================================================

#define BAUD_RATE    115200
#define HEADER       0xAA
#define SERIAL1_RX   20      // D7 sur XIAO ESP32-C3
#define SERIAL1_TX   21      // D6 sur XIAO ESP32-C3

typedef enum {
    WAIT_HEADER,
    WAIT_LEN,
    WAIT_DATA,
    WAIT_CHECKSUM
} rx_state_t;

rx_state_t rx_state     = WAIT_HEADER;
uint8_t    payload[8];
uint8_t    byte_idx     = 0;
uint8_t    expected_len = 0;
uint8_t    checksum_acc = 0;
bool       ch_toggle    = false;

// Statistiques
uint32_t frames_ok  = 0;
uint32_t frames_err = 0;

void setup() {
    Serial.begin(115200);
    unsigned long t = millis();
    while (!Serial && millis() - t < 2000);

    Serial1.begin(BAUD_RATE, SERIAL_8N1, SERIAL1_RX, SERIAL1_TX);

    Serial.println("=== UART Framer Receiver ===");
    Serial.print("RX=GPIO"); Serial.print(SERIAL1_RX);
    Serial.print(" TX=GPIO"); Serial.println(SERIAL1_TX);
    Serial.println("Format sortie : canal,valeur");
    Serial.println("============================");
}

void loop() {
    while (Serial1.available()) {
        uint8_t b = (uint8_t) Serial1.read();

        switch (rx_state) {

            case WAIT_HEADER:
                if (b == HEADER) rx_state = WAIT_LEN;
                break;

            case WAIT_LEN:
                expected_len = b;
                byte_idx     = 0;
                checksum_acc = 0;
                rx_state     = WAIT_DATA;
                break;

            case WAIT_DATA:
                payload[byte_idx++] = b;
                checksum_acc ^= b;
                if (byte_idx == expected_len) rx_state = WAIT_CHECKSUM;
                break;

            case WAIT_CHECKSUM:
                if (b == checksum_acc) {
                    // Reconstruction valeur 12 bits (LSB en payload[0], MSB en payload[1])
                    uint16_t val = (((uint16_t)payload[1] << 8) | payload[0]) & 0x0FFF;
                    Serial.print(ch_toggle ? "1," : "0,");
                    Serial.println(val);
                    ch_toggle = !ch_toggle;
                    frames_ok++;
                } else {
                    // Checksum invalide : trame corrompue
                    frames_err++;
                    // Décommenter pour debug :
                    // Serial.print("ERR CS got=0x");
                    // Serial.print(b, HEX);
                    // Serial.print(" exp=0x");
                    // Serial.println(checksum_acc, HEX);
                }
                rx_state = WAIT_HEADER;
                break;
        }
    }
}

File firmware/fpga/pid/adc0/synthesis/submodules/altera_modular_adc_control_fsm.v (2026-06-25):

// (C) 2001-2019 Intel Corporation. All rights reserved.
// Your use of Intel Corporation's design tools, logic functions and other 
// software and tools, and its AMPP partner logic functions, and any output 
// files from any of the foregoing (including device programming or simulation 
// files), and any associated documentation or information are expressly subject 
// to the terms and conditions of the Intel Program License Subscription 
// Agreement, Intel FPGA IP License Agreement, or other applicable 
// license agreement, including, without limitation, that your use is for the 
// sole purpose of programming logic devices manufactured by Intel and sold by 
// Intel or its authorized distributors.  Please refer to the applicable 
// agreement for further details.


// (C) 2001-2016 Intel Corporation. All rights reserved.
// Your use of Intel Corporation's design tools, logic functions and other 
// software and tools, and its AMPP partner logic functions, and any output 
// files any of the foregoing (including device programming or simulation 
// files), and any associated documentation or information are expressly subject 
// to the terms and conditions of the Intel Program License Subscription 
// Agreement, Intel MegaCore Function License Agreement, or other applicable 
// license agreement, including, without limitation, that your use is for the 
// sole purpose of programming logic devices manufactured by Intel and sold by 
// Intel or its authorized distributors.  Please refer to the applicable 
// agreement for further details.


// synthesis translate_off
`timescale 1ns / 1ps
// synthesis translate_on

module altera_modular_adc_control_fsm #(
    parameter is_this_first_or_second_adc = 1,
    parameter dual_adc_mode = 0
) (
    input               clk, 
    input               rst_n,
    input               clk_in_pll_locked,
    input               cmd_valid,
    input [4:0]         cmd_channel,
    input               cmd_sop,
    input               cmd_eop,
    input               clk_dft,
    input               eoc,
    input [11:0]        dout,
    input               sync_ready,

    output reg          rsp_valid,
    output reg [4:0]    rsp_channel,
    output reg [11:0]   rsp_data,
    output reg          rsp_sop,
    output reg          rsp_eop,
    output reg          cmd_ready,
    output reg [4:0]    chsel,
    output reg          soc,
    output reg          usr_pwd,
    output reg          tsen,
    output reg          sync_valid

);

reg [4:0]   ctrl_state;
reg [4:0]   ctrl_state_nxt;
reg         clk_dft_synch_dly;
reg         eoc_synch_dly;
reg [4:0]   chsel_nxt;
reg         soc_nxt;
reg         usr_pwd_nxt;
reg         tsen_nxt;
reg         prev_cmd_is_ts;
reg         cmd_fetched;
reg         pend;
reg [4:0]   cmd_channel_dly;
reg         cmd_sop_dly;
reg         cmd_eop_dly;
reg [7:0]   int_timer;
reg [17:0]  avrg_sum;
reg         avrg_cnt_done;
reg         frst_64_ptr_done;
reg         conv_dly1_s_flp;
reg [11:0]  dout_flp;
reg [4:0]   prev_ctrl_state;
reg [4:0]   sync_ctrl_state;
reg [4:0]   sync_ctrl_state_nxt;

wire        clk_dft_synch;
wire        eoc_synch;
wire        clk_dft_lh;
wire        clk_dft_hl;
wire        eoc_hl;
wire        cmd_is_rclb;
wire        cmd_is_ts;
wire        arc_conv_conv_dly1;
wire        arc_sync1_conv_dly1;
wire        arc_wait_pend_wait_pend_dly1;
wire        arc_sync1_wait_pend_dly1;
wire        arc_to_conv;
wire        arc_to_avrg_cnt;
wire        load_rsp;
wire        load_cmd_ready;
wire        arc_getcmd_w_pwrdwn;
wire        arc_getcmd_pwrdwn;
wire        load_cmd_fetched;
wire        load_int_timer;
wire        incr_int_timer;
wire        arc_out_from_pwrup_soc;
wire        clr_cmd_fetched;
wire        adc_change_mode;
wire        add_avrg_sum;
wire        add_avrg_sum_run;
wire        clear_avrg_sum;
wire        clear_avrg_cnt_done;
wire        set_frst_64_ptr_done;
wire        clear_frst_64_ptr_done;
wire [11:0] fifo_q;
wire        fifo_sclr;
wire        fifo_rdreq;
wire        fifo_wrreq;
wire        putresp_s;
wire        putresp_pend_s;
wire        pwrdwn_s;
wire        pwrdwn_tsen_s;
wire        avrg_cnt_s;
wire        wait_pend_dly1_s;
wire        conv_dly1_s;
wire        conv_s;
wire        putresp_dly3_s;
wire        load_dout;
wire        avrg_enable;
wire [11:0] rsp_data_nxt;

localparam [4:0]    IDLE                = 5'b00000;
localparam [4:0]    PWRDWN              = 5'b00001;
localparam [4:0]    PWRDWN_TSEN         = 5'b00010;
localparam [4:0]    PWRDWN_DONE         = 5'b00011;
localparam [4:0]    PWRUP_CH            = 5'b00100;
localparam [4:0]    PWRUP_SOC           = 5'b00101;
localparam [4:0]    WAIT                = 5'b00110;
localparam [4:0]    GETCMD              = 5'b00111;
localparam [4:0]    GETCMD_W            = 5'b01000;
localparam [4:0]    PRE_CONV            = 5'b01001;
localparam [4:0]    CONV                = 5'b01010; // Drive chsel. Get out of this state when falling edge of EOC detected (DOUT is ready for sample)
                                                    // Read averaging fifo.
                                                    // Capture DOUT into dout internal buffer register (dout_flp) 
localparam [4:0]    CONV_DLY1           = 5'b01011; // Additional state for processing when DOUT is ready. Perform averaging calculation (adds and minus operation). 
localparam [4:0]    PUTRESP             = 5'b01100; // Load response
localparam [4:0]    PUTRESP_DLY1        = 5'b01101;
localparam [4:0]    PUTRESP_DLY2        = 5'b01110;
localparam [4:0]    PUTRESP_DLY3        = 5'b01111;
localparam [4:0]    WAIT_PEND           = 5'b10000; // Get out of this state when falling edge of EOC detected (DOUT is ready for sample)
                                                    // Read averaging fifo.
                                                    // Capture DOUT into dout internal buffer register (dout_flp) 
localparam [4:0]    WAIT_PEND_DLY1      = 5'b10001; // Additional state for processing when DOUT is ready. Perform averaging calculation (adds and minus operation).
localparam [4:0]    PUTRESP_PEND        = 5'b10010; // Load response
localparam [4:0]    AVRG_CNT            = 5'b10011;
localparam [4:0]    SYNC1               = 5'b10100; // Allocates 1 soft ip clock mismatch due to asynchronous between soft ip clock and ADC clock domain

localparam [7:0]    NUM_AVRG_POINTS     = 8'd64;

//--------------------------------------------------------------------------------------------//
// Double Synchronize control signal from ADC hardblock
//--------------------------------------------------------------------------------------------//
altera_std_synchronizer #(
    .depth    (2)
) u_clk_dft_synchronizer (
    .clk        (clk),
    .reset_n    (rst_n),
    .din        (clk_dft),
    .dout       (clk_dft_synch)
);
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

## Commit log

2026-06-25 Ajout fichiers CAO Fusion360
    [pince.f3z, robot.f3z]
2026-06-25 Ajout de fichiers PADS
    [pcb.sch]
2026-06-25 Ajout pid

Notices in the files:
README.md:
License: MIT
